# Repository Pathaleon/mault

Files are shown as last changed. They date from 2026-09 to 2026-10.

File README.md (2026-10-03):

# Magic Vault

A TCG card scanner and physical sorter. A webcam identifies cards via AI image embeddings, a rule engine decides which bin each card belongs in, and a feeder and servo mechanism driven by an Arduino or ESP32 physically routes the card there.

## Supported TCGs

Magic: The Gathering, Pokemon, Yu-Gi-Oh, One Piece, Lorcana, Gundam, Flesh and Blood, Riftbound

## MakerWorld

https://makerworld.com/en/models/3066180-tcg-card-sorting-machine

## How it works

1. A feeder mechanism (continuous-rotation servo + roller) pulls a card from the hopper into view of the webcam, into a fixed, per-camera-calibrated scan region (see calibration screen) used as a coarse hint for step 2
2. The browser locates the card's four corners and perspective-dewarps it to a straightened crop, then embeds it, all client-side via [CollectorVision](https://github.com/HanClinto/CollectorVision)'s Cornelius (corner detection) and Milo (embedding) ONNX models running in-browser
3. The embedding is sent to the server for similarity search (or, if the client can't run the on-device models, the raw image is sent for server-side embedding instead)
4. PostgreSQL vector similarity search (pgvector) identifies the card
5. Configurable, per-collection bin rules decide which bin the card should go to
6. The web app sends a serial command to the microcontroller, which drives the trapdoor/paddle/pusher servos to route the card into that bin

## Features

- Live webcam scanning with automatic card detection and identification; captures wait for the card to physically settle at the sensor before the shot is taken
- Multi-TCG support: pluggable card-search adapters per game, with each game's own admin-configurable field definitions driving sorting, filtering, and bin rules
- Rule-based sort bins, grouped by collection, with and/or rule trees across each game's own card fields (color, rarity, price, set, etc.)
- Override rules let a matching bin take priority over ordinary bins. For example, enable **Override rules** on bin 6 with a price condition of **greater than or equal to 1** to send cards worth $1+ there before checking color bins 1–5. If multiple override bins match, the lowest bin number wins; unmatched cards still use the catch-all.
- Card grid sorting (by name, price, rarity, etc.) adapts automatically to whichever game a collection uses
- Multiple collections per organization, each with their own bin configuration and card history
- Remote monitoring: watch an in-progress scan session live from another device
- Discord bot: link a Discord server to an organization with `/link` and a code from the Integrations page, then anyone in it can run `/stats` (optionally scoped to one collection via autocomplete) to check collection stats. Everything else is set up in the app's Integrations page: which channels get every scan and every error or alert (server-wide or per collection), and notification rules that post matching cards to their own channels. No webhook URLs to configure
- Per-organization branding and scanner layout settings
- Feeder, servo, and camera scan-region calibration tools: the camera's capture region can be dragged/resized live against the feed to match different webcam mountings and fields of view
- In-app hardware build guide (`/build`) with bill of materials, wiring diagrams, and assembly instructions

## Stack

- **Web**: React 19, Vite, React Router v7, Tailwind CSS 4, TanStack Query
- **Server**: Hono 4, Drizzle ORM, PostgreSQL (pgvector) — either Neon-hosted or self-hosted
- **Auth**: two interchangeable providers, picked with `AUTH_PROVIDER` — [Neon Auth](https://neon.com) (JWT, hosted) or [own-auth](https://own-auth.com) (self-hosted, bearer tokens against your own Postgres); see [Choosing a provider](#choosing-a-provider)
- **Hardware**: Arduino Uno R4 or ESP32 via Web Serial API (9600 baud), PCA9685 servo driver
- **Monorepo**: Turborepo + pnpm workspaces

## Project structure

```
packages/
├── shared/   @magic-vault/shared - types, constants, evaluate-bin rule engine
├── server/   @magic-vault/server - Hono API, Drizzle schema/db, auth middleware
├── web/      @magic-vault/web    - React SPA (scanner, bins, collections, admin, build guide)
└── bot/      @magic-vault/bot    - Discord bot (slash commands), talks to the server's HTTP API only
firmware/     Arduino/ESP32 sketch (firmware/main/main.ino)
"3d model"/   Printable enclosure/module design (Fusion 360 + .3mf)
drizzle/      Generated SQL migrations
scripts/      Release/version-bump helpers
```

## Getting started

### Choosing a provider

The app needs a Postgres database with pgvector (for card-embedding search) and an identity provider (for login + row-level security), selected by `AUTH_PROVIDER`/`VITE_AUTH_PROVIDER`:

- **`neon`** (default) — a hosted [Neon](https://neon.com) project. A few minutes of console setup, then `pnpm dev`. Neon's free tier is enough for a personal/single-org deployment.
- **`local`** — fully self-hosted, no external account, works offline. `docker-compose.yml` runs the whole stack (Postgres+pgvector, API, web app) with [own-auth](https://own-auth.com) handling sign-up/sign-in against that same self-hosted Postgres.

Both providers read from the same root `.env` (Vite is configured to read up from `packages/web`, so there's no separate `packages/web/.env`):

```bash
cp .env.neon.example .env      # Option A: Neon
cp .env.docker.example .env    # Option B: self-hosted
```

Each file holds only the variables its provider uses, with `AUTH_PROVIDER`/`VITE_AUTH_PROVIDER` already set.

### Option A: Neon

1. Create a Neon project at [console.neon.tech](https://console.neon.tech) (any recent Postgres version works; pgvector ships as a bundled extension).
2. Open the SQL editor on your project's default branch/database and enable pgvector:
   ```sql
   CREATE EXTENSION IF NOT EXISTS vector;
   ```
3. Copy the pooled connection string (Dashboard → Connect) into `DATABASE_URL`.
4. Enable **Neon Auth** for the project (Dashboard → Auth). This provisions the `auth` schema, the `authenticated` Postgres role, and `auth.user_id()` — the row-level-security policies in `drizzle/*.sql` reference these directly, so Auth must be enabled _before_ you run migrations or `db:push` (step below), or they'll fail with an undefined function/role error.
5. From the Auth page, grab:
   - `NEON_AUTH_URL` — the base Auth URL (the server derives the JWKS endpoint and JWT issuer from it: `${NEON_AUTH_URL}/.well-known/jwks.json`)
   - `VITE_NEON_AUTH_URL` — same Auth base URL, used client-side by the Better Auth React client
   - `VITE_NEON_DATA_API_URL` — the project's Data API URL, also from the Auth page
6. Run `pnpm --filter @magic-vault/server db:push` (or `db:generate` + `db:migrate`, see [Database](#database)) to create the schema and RLS policies against your new database.
7. Install and run:
   ```bash
   pnpm install
   pnpm dev        # Vite on :5173, Hono on :3001
   ```

### Option B: Self-hosted (no Neon account, works offline)

1. In `.env` (copied from `.env.docker.example`), fill in:
   - `POSTGRES_PASSWORD` — the local Postgres container's password
   - `OWN_AUTH_TOKEN_PEPPER` — 32+ random bytes; own-auth uses it to hash sessions/tokens/API keys
   - `IMPERSONATION_SECRET` — any random string
   - `MONITOR_LINK_SECRET` — any random string (optional; enables shareable no-login monitor links)
2. Start the stack:
   ```bash
   docker compose up -d
   ```
3. Open `http://localhost:8080` and sign up. The first account ever created on a fresh instance is automatically made platform admin (Games Manager, sync job, impersonation) and gets a default "Home" organisation — from there, add at least one game in the admin Games Manager (`/app/admin`) and run its sync before scanning, or collections/scanning have nothing to match against.

Prices (TCGplayer USD and Cardmarket EUR) come from the `prices` container, which starts with the stack, pulls on start and then checks every `PRICE_SYNC_INTERVAL_HOURS` (6 by default), only downloading what changed upstream. Prices attach to synced cards, so run a game's sync from `/app/admin` first; until then, or until the first pull finishes, cards show no price. Watch it with `docker compose logs -f prices`, or force a full re-pull with `docker compose exec prices node packages/server/dist/scripts/sync-prices.js --force`.

The `server` container applies Drizzle migrations, own-auth's own migrations, and the RLS bootstrap (`packages/server/src/db/bootstrap-local.sql`, run via `pnpm db:migrate-local` — see that script for why plain Postgres needs a few things Neon normally provisions automatically) on every start; all three steps are idempotent.

To grant a _second_ admin, update their row in `platform_user_roles` directly — there's no UI for it yet:

```sql
INSERT INTO platform_user_roles (user_id, role) VALUES ('<their own_auth_users.id>', 'admin')
ON CONFLICT (user_id) DO UPDATE SET role = 'admin';
```

Local mode covers sign-up/sign-in/sign-out/session/org-switch, its own org invite UI, personal API keys, and an org audit log — email verification, profile/password editing, and multi-device session management stay Neon-only for now (see `CLAUDE.md`'s Auth & RLS section).

## Database

```bash
pnpm --filter @magic-vault/server db:generate  # generate a migration from schema changes
pnpm --filter @magic-vault/server db:migrate   # apply migrations
pnpm --filter @magic-vault/server db:push      # push schema directly (dev)
pnpm --filter @magic-vault/server db:studio    # open Drizzle Studio
```

These target whichever Postgres `DATABASE_URL` points at. Self-hosted mode's container applies migrations automatically (see [Option B](#option-b-self-hosted-no-neon-account-works-offline)) — you only need these commands by hand against Neon, or after changing `packages/server/src/db/schema.ts`.

## Deployment

`Dockerfile.server` builds the Hono API (and pre-downloads the pinned CollectorVision Milo model at build time — `packages/server/src/lib/models/model-registry.ts`). `Dockerfile.web` builds the Vite SPA and serves it with nginx (`nginx.conf`); `VITE_API_URL` (and `VITE_AUTH_PROVIDER`) must be supplied as build args since they're baked into the client bundle. `Dockerfile.bot` builds the optional Discord bot — it talks to the server over HTTP (`SERVER_URL`), never the database directly, but the connection is bidirectional: the server also calls back into the bot's own small HTTP server (`BOT_PORT`, exposed to the server as `BOT_URL`) to post every notification into whichever channel was set with `/notify-channel` (errors, jams, sync failures) or `/scan-channel` (card scans), or for Buy Me a Coffee donations (`routes/public.ts`'s `/webhooks/buymeacoffee`, unauthenticated but HMAC-verified rather than org-linked). Both directions share `BOT_API_SECRET`.

> If you're running a Pi-hole or similar DNS-level blocker on your network, it may block `huggingface.co`, which will cause the Milo model download to fail. Allowlist that domain if you hit download errors during the server build/startup.

### Deploying self-hosted

The same `docker compose up -d` flow from [Option B](#option-b-self-hosted-no-neon-account-works-offline) is the production deployment too — just point `WEB_URL` at your public URL, and use a real `POSTGRES_PASSWORD`/`OWN_AUTH_TOKEN_PEPPER`/`IMPERSONATION_SECRET` rather than dev placeholders.

```bash
docker compose up --build -d              # server + web + price sync + local Postgres
docker compose --profile bot up --build -d  # + Discord bot
```

Inside compose the server and bot reach each other by service name (`http://server:3001`, `http://bot:3002`), so the `SERVER_URL`/`BOT_URL` values in `.env` (which point at localhost for `pnpm dev`) are overridden there. If you already run `sync-prices` from your own scheduler, set `PRICE_SYNC_INTERVAL_HOURS=0` so the `prices` container doesn't pull too.

### Deploying with Neon

For the Neon-backed deployment (`AUTH_PROVIDER=neon`, the default), the database and auth still need a [Neon project](#option-a-neon) set up first, and its connection details passed to the server container as env vars (`DATABASE_URL`, `NEON_AUTH_URL`, `WEB_URL`) and to the web build as build args (`VITE_API_URL`, `VITE_NEON_AUTH_URL`, `VITE_NEON_DATA_API_URL`, `VITE_APP_ENV`, `VITE_LATEST_FIRMWARE_VERSION`). A minimal setup:

```bash
docker build -f Dockerfile.server -t magic-vault-server .
docker run -p 3001:3001 --env-file .env magic-vault-server

docker build -f Dockerfile.web \
  --build-arg VITE_API_URL=https://your-api-host \
  --build-arg VITE_NEON_AUTH_URL=$VITE_NEON_AUTH_URL \
  --build-arg VITE_NEON_DATA_API_URL=$VITE_NEON_DATA_API_URL \
  --build-arg VITE_APP_ENV=production \
  --build-arg VITE_LATEST_FIRMWARE_VERSION=1.0.2 \
  -t magic-vault-web .
docker run -p 8080:80 magic-vault-web
```

Point `WEB_URL` (server env) at the public URL of the web container so CORS and Discord monitor-page links resolve correctly, and re-run `db:push`/`db:migrate` against the Neon database as part of your deploy if the schema changed.

The same `docker-compose.yml` from [Option B](#option-b-self-hosted-no-neon-account-works-offline) can wire the three images together this way too (server on :3001, web on :8080, and the optional bot on :3002) — `AUTH_PROVIDER` in `.env` just needs to be `neon` (the default) rather than `local`:

```bash
docker compose up --build
docker compose --profile bot up --build  # + Discord bot
```

`.env` must already point `DATABASE_URL`/`NEON_AUTH_URL` at a real Neon project — the `postgres` service in `docker-compose.yml` still starts alongside it, but sits unused since nothing points at it in this mode.

## Hardware

The full bill of materials, wiring diagrams, and assembly instructions live in the app at `/build`. In short:

- Arduino Uno R4 or ESP32 Dev Module, driving a PCA9685 servo controller over I2C
- 3 positional SG90 servos per sorting module (trapdoor, paddle gate, pusher) plus 1 continuous-rotation SG90 for the feeder — module count is configurable (up to 5 on a single PCA9685) in Calibration
- IR sensor for card-feed detection
- Enclosure and module parts are in `3d model/` (Fusion 360 source + printable `.3mf`)

Upload `firmware/main/main.ino` (requires the ArduinoJson library) to either board via the Arduino IDE — see `/build` for the full flashing steps and per-board pin/wiring differences. The sketch is always compiled for the full module ceiling a single PCA9685 supports — it doesn't need to match how many modules you've actually built, since the app already knows each org's real module count and only ever sends route commands for modules that exist, so you can add modules later without reflashing. It communicates via JSON over USB serial: the web app sends `{"route": {"module": N, "direction": "left"|"right"|"bottom"}}`, resolved from the bin's routing assignment in Calibration, and the board runs the routing sequence. `"bottom"` advances the card through each preceding module (same as `"left"`/`"right"`) and drops it through the target module's own bottom output, rather than a shared catch-all — any bin can be assigned to any module's bottom output.

Where module 1 starts on the PCA9685 is also runtime-configurable, not baked into the firmware: a "PCA9685 channel layout" toggle in Calibration (Standard = channel 0, up to 5 modules; Legacy = channel 4, reserving 0-3 for the status LEDs older firmware drove, up to 3 modules) sends `{"setChannelOffset": N}` once per connection. Orgs with pre-existing module calibration data default to Legacy so already-wired hardware keeps working unchanged; new orgs default to Standard.

## Webcam

Using a Logitech C920, these settings worked best:

Auto Focus: Off
Focus: 50%
Auto Exposure: On
Low Light Compensation: On
Auto White Balance: On
Brightness: 140
Contrast: 140
Saturation: 160
Sharpness: 130

## Licensing

This repository contains multiple components with different licenses.

| Component | License |
| --- | --- |
| Software source code | MIT License |
| 3D models (`/3d model`) | CC BY-NC-SA 4.0 |

See the `LICENSE` file in each directory for the complete license terms.

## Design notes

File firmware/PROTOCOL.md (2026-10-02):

# Sorting Machine Communication Protocol

This documents the serial wire protocol implemented by the sorting
machine's firmware (`main/main.ino`), running on an Arduino Uno R4
(the current build docs/BOM target) or an ESP32 (see the
`ARDUINO_ARCH_ESP32` pin block in `main.ino`). Any client that can open
a serial connection to the device can drive it by following this spec
— it does not assume any particular host language or application.

## Transport

- **9600 baud**. Uno R4 uses native USB CDC serial; most ESP32
  boards instead go through a UART-to-USB bridge chip, which looks
  identical to a client opening the port but does **not** share the
  Uno's reconnect-without-reset behavior described below — a host
  closing and reopening the port on one of those boards does reset the
  sketch (same as a classic Uno), so `{"getStatus": true}` still works
  either way but isn't the only source of a fresh ready/version line.
- ESP32-S2/S3 boards have their own native USB (no bridge chip). They
  must be built with **"USB Mode: Hardware CDC and JTAG"** and **"USB CDC
  On Boot: Enabled"** (`USBMode=hwcdc,CDCOnBoot=cdc` on the arduino-cli
  FQBN - see `firmware-release.yml`), and the client must be plugged into
  the chip's native USB port rather than a secondary UART-only port some
  of these boards also expose. This firmware used to instead own a
  manually-created `USBCDC`/USB-OTG connection so the device could report
  a custom "Mault Card Sorter" name, but that mode's software
  bootloader-reset handshake hits an unresolved upstream bug when
  connected directly to a PC (github.com/espressif/arduino-esp32#10204),
  which made this app's in-browser flashing (`use-serial.tsx`'s
  `flashEsp32`) unreliable. Hardware CDC/JTAG mode's reset handshake
  doesn't hit that bug, at the cost of the device enumerating under a
  fixed Espressif name/VID/PID instead of a custom one. Classic ESP32
  (WROOM/WROVER) has no native USB at all, so its bridge chip's fixed
  descriptor is what shows up instead - not something this firmware can
  change.
- **Framing:** one JSON object per line, terminated by `\n` (`\r` is
  also accepted as a line terminator). Every request produces exactly
  **one** JSON-line response, in the order it was sent — there is no
  request ID, so a client must correlate responses positionally (send
  one command, read one response line, before sending the next).
- **One command at a time, across every transport.** While a command is
  executing (a `route` can take several seconds), the device keeps reading
  input and answers any new line immediately with
  `{"error":"busy","reason":"another command is in progress"}`, without
  running it. That rejection arrives **before** the in-progress command's own
  response, so a client that sent a second command while waiting on a first
  must match the `busy` reply to the second one, not the first. Nothing is
  queued: resend once the first response has arrived. One exception: on the
  Uno R4 WiFi (ArduinoBLE backend), BLE input can't be read while a
  BLE-originated command is running, so a BLE line sent during a BLE command
  is only read (and then run normally) once that command finishes.
- A line longer than 255 characters is discarded and answered with
  `{"error":"command too long"}`.
- Malformed JSON gets `{"error":"invalid JSON","reason":"...","length":N,"received":"<escaped input>"}`.
- An unrecognized (but validly-parsed) command gets `{"error":"unknown command"}`.
- On power-up the device prints
  `{"status":"ready","version":"1.0.2","board":"esp32","id":"A1B2C3"}`
  unprompted, before any command is sent. `board` is `"esp32"` or `"uno_r4"`
  - the app uses it to decide whether the device can be reflashed from the
  browser (ESP32 only) or needs a link to the GitHub repo instead. `id` is
  a short (6 hex character) identifier for this specific physical board -
  the same value over Serial or BLE, and stable across power cycles and
  re-flashes, so a client can key a saved configuration to the board it's
  actually talking to. Sourced from whatever's factory-unique on the board
  (its Wi-Fi/BT MAC on ESP32 and the Uno R4 WiFi - see BLE transport below),
  falling back to a random value generated once and persisted to EEPROM on
  the Uno R4 Minima, which has no radio at all to read an address from.
- One other message is **unsolicited** and can arrive at any time
  between command/response pairs: `{"error":"jam","module":N}`, pushed
  if module *N*'s IR sensor sees a card continuously for 20 seconds
  with no servo activity (firmware 2.2.1+: the clock restarts on any
  servo move, so back-to-back cards fed in during a `feedNext` route never
  add up to a false jam; older firmware timed from when the sensor was
  last seen empty). A client should watch for this
  independently of whatever response it's waiting on. This check is
  purely informational - it doesn't move any servos, since nothing is
  actively trying to sort that card. Paddle-flap recovery only happens
  inline during an active `route`, on a card that fails to advance to
  the next module in time (see `route` below).
- A `route` sent with `"feedNext": true` (firmware 2.1.0+) also emits one
  `{"event":"fed",...}` line **before** its own response (see `route`
  below). Any line carrying an `event` key is never a command's
  response, so a client correlating responses positionally must skip it.

- Uno R4 builds run a hardware watchdog (about 4s). If the board ever
  hangs mid-command (typically a supply dip from servos wedging the MCU or
  its I2C bus), it reboots instead of going silent: the pending command
  never gets a response, USB/BLE drops, and the boot banner is sent again
  once a client reconnects. Configuration is back to defaults after that,
  so a client must re-send it exactly as on a fresh connect.

## BLE transport

ESP32-S3 and Uno R4 WiFi builds also advertise a BLE peripheral, so a client
can drive the device wirelessly instead of over USB - Uno R4 Minima has no
BLE hardware and is Serial-only. This carries the **exact same** line-
delimited JSON protocol documented below; only how bytes get to/from the
device differs. `main.ino`'s two backends (`ble_arduinoble.ino` for the Uno
R4 WiFi, `ble_esp32.ino` for the ESP32-S3) implement this identically from a
protocol standpoint.

- **Service:** the well-known Nordic UART Service (NUS) UUIDs, reused rather
  than inventing custom ones so generic BLE terminal apps (nRF Connect, etc.)
  can talk to the device for debugging without any app-specific tooling.
  - Service: `6E400001-B5A3-F393-E0A9-E50E24DCCA9E`
  - RX characteristic (write / write-without-response — commands in):
    `6E400002-B5A3-F393-E0A9-E50E24DCCA9E`
  - TX characteristic (notify — responses and unsolicited messages out):
    `6E400003-B5A3-F393-E0A9-E50E24DCCA9E`
- **Framing:** identical to Serial — one JSON object per line, `\n`-
  terminated. A single command or response line is **not** guaranteed to
  arrive in one BLE write/notify packet: both directions get chunked to the
  connection's negotiated MTU (the device chunks conservatively at 20 bytes
  unless testing shows a given board/central negotiates higher), so a client
  must reassemble by simply appending received bytes to a buffer and
  splitting on `\n`, exactly as it already does for Serial's byte stream.
- **Response routing:** a command's response is sent back only on the
  transport it arrived on — if both Serial and BLE are connected at once,
  each keeps its own independent request/response correlation (the protocol
  has no request IDs, so a client must still send one command and read one
  response before sending the next — see Transport above). The boot banner
  and the unsolicited `{"error":"jam",...}` message are the exception: they
  broadcast to every currently-connected transport, not just one.
- **Reliability:** BLE notifications aren't guaranteed delivery. A dropped
  chunk mid-line corrupts that one response; a client's existing timeout-
  based recovery (waiting for a response line, per the framing note above)
  handles this as a failed/garbled response, but there's no automatic retry
  of the specific request. This matches how generic BLE UART bridges behave.
- **Power-only operation:** BLE works with no USB host at all (e.g. only
  VIN powered). On boot the firmware waits at most 1.5s for a USB serial
  host before starting BLE, and on ESP32-S3 Hardware CDC builds USB writes
  never block when no host is attached. Without a USB host the boot banner
  only goes out over BLE once a central connects, so a client should send
  `{"getStatus": true}` after connecting.
- **Advertised name:** `"Mault Sorter XXXXXX"`, where `XXXXXX` is the same
  `id` reported in `getStatus`/the boot banner (see Transport above) - on
  these two boards, sourced from the BLE MAC (`BLE.address()` on the Uno R4
  WiFi's ArduinoBLE backend, `esp_read_mac(..., ESP_MAC_WIFI_STA)` on the
  ESP32-S3 Bluedroid backend, read before BLE even advertises). This exists
  so multiple physical units show up as distinct entries in a phone/OS
  Bluetooth picker before a client ever connects to one.

## Hardware model

- A **module** is one physical sorting stage: three positional SG90
  servos (`bottom` = trapdoor, `paddle` = gate, `pusher` = arm) plus its
  own IR sensor, occupying 3 consecutive channels on the onboard PCA9685
  servo driver (module *N* → channels `(N-1)*3 .. (N-1)*3+2`, shifted by
  the active channel offset).
- The **feeder** is a separate continuous-rotation servo on the channel
  right after the last addressable module, plus its own hopper IR sensor
  (separate from any module's IR) that reports whether cards remain in
  the stack.
- The channel offset (set via `setChannelOffset`) is `0` ("standard",
  up to 5 modules) or `4` ("legacy", up to 3 modules — channels 0-3 are
  reserved for older status LEDs on that layout). It must be set once
  per connection, before any other command, because it determines how
  many modules exist and therefore which module numbers are valid.
- The firmware has no concept of a "bin" — only modules and directions.
  A client that wants bin-style routing (mapping arbitrary logical bins
  to physical outputs) needs to keep that mapping on its own side and
  translate it to a `route` command.

## Recommended connection sequence

1. Open the serial port at 9600 baud.
2. Send `{"getStatus": true}` and read the response to confirm the
   device is alive and check its firmware `version`. Also useful after
   reopening a port without a physical power cycle: on native-USB boards
   (Uno R4) the sketch doesn't reset and won't print a fresh boot
   message on its own, so this is the only way to get one; on
   UART-bridge boards (most ESP32s) reopening does reset the sketch and
   print one unprompted, but sending this is still harmless and confirms
   the version either way.
3. Send `{"setChannelOffset": 0}` or `{"setChannelOffset": 4}` depending
   on which physical layout the machine uses.
4. Optionally push any calibration you want to (re)apply via `setConfig`
   / `setFeederConfig` — the device only remembers calibration for as
   long as it stays powered, so a client is responsible for restoring it
   after every reset.
5. Optionally run `{"test": true}` to sanity-check every servo before
   normal operation.

## Commands

All requests are single-line JSON objects, keyed on which top-level
field is present.

### `getStatus`
```json
{"getStatus": true}
```
→ `{"status":"ready","version":"1.0.2","board":"esp32","id":"A1B2C3"}`

Firmware 2.2.2+ adds `"ble"` to this line and to the boot banner:
`"advertising"` (BLE is up and discoverable), `"connected"` (a central is
connected, so the device isn't advertising, since ArduinoBLE and this
firmware's Bluedroid backend accept one connection at a time),
`"unavailable"` (the BLE stack failed to start, e.g. the Uno R4 WiFi's
co-processor didn't answer `BLE.begin()` after 5 attempts; the device keeps
working over Serial), or `"none"` (a board with no BLE hardware, such as the
Uno R4 Minima).

### `setChannelOffset`
```json
{"setChannelOffset": 0}
```
`0` = standard layout, `4` = legacy layout. Also resets every servo to
neutral. → `{"status":"ok"}`

### `test`
```json
{"test": true}
```
Runs a full self-test sequence: opens every module's bottom + paddle →
sweeps every pusher left → sweeps every pusher right → resets all to
neutral → briefly spins the feeder (500ms) → stops it.
→ `{"status":"test_complete"}`

Refuses to run (and reports which module) if any module's gate sensor
already reads a card present, since the sequence sweeps every
trapdoor/paddle/pusher without regard for something already sitting in the
mechanism - clear it first (`clearDevice`) and retry. Doesn't check the
hopper sensor, since cards waiting to be fed are a normal state, not a jam.
→ `{"error":"module 2 sensor is blocked - clear the device before testing","module":2}`

### `neutral`
```json
{"neutral": true}
```
Resets every module's bottom/paddle/pusher to closed/closed/neutral and
stops the feeder. → `{"status":"ok"}`

### `clearDevice`
```json
{"clearDevice": true}
```
Opens **every** module's bottom trapdoor at once (useful for flushing a
physically stuck card), then resets to neutral. → `{"status":"cleared"}`

### `servo` (manual single-servo move)
```json
{"servo": "bottom", "module": 1, "position": "open"}
```
or, to bypass calibrated positions and drive a raw pulse directly:
```json
{"servo": "bottom", "module": 1, "value": 250}
```
- `servo`: `"bottom" | "paddle" | "pusher"`
- `position`: `"open" | "closed"` (bottom/paddle), `"left" | "neutral" | "right"` (pusher)
- `value`: raw PWM pulse, clamped to `120–490`

→ `{"status":"ok","servo":"bottom","module":1}`, or
`{"error":"servo must be bottom, paddle, or pusher"}` /
`{"error":"invalid position"}` / `{"error":"module must be 1 to N"}`

#### Push safeguard (firmware 2.2.0+, always on since 2.3.0)

A pusher never moves off neutral unless its module's side paddle has been
commanded to its calibrated `paddleOpen` position and has had
`DELAY_PADDLE` (300 ms) to get there. The firmware has no paddle position
sensor, so it tracks the last position it commanded: any other paddle
pulse, or the idle servo release, counts as not open.

Since 2.3.0 this is enforced inside the firmware's single servo write path,
so it covers every pusher move (`servo`, `channel` writes that land on a
module's pusher channel, `route`, `pushTest`, the connect `test`) whether or
not a card is on the platform. Instead of refusing, a pusher move with the
paddle not known to be down lowers the paddle itself, waits out the rest of
`DELAY_PADDLE`, then moves the pusher, so the command just takes up to
300 ms longer and the paddle is left lowered. Returning a pusher to neutral
never touches the paddle.

2.2.x only applied the check while the module's IR sensor read a card, and
refused the move with
`{"error":"push_blocked","reason":"lower the side paddle before pushing a card","module":N}`
instead of lowering the paddle. 2.3.0+ never sends `push_blocked`; clients
still handle it for older firmware.

### `channel` (raw PCA9685 channel test)
```json
{"channel": 7, "value": 300}
```
Drives PCA9685 channel `channel` (0-15) at raw pulse `value` directly,
bypassing the module/servo mapping (`getChannel()`) and its module-range
validation entirely — unlike `servo` above, this works on a channel that
isn't wired into any module yet. For verifying a servo/channel works, or
finding which channel a given wire is on, during assembly or troubleshooting.
- `value`: raw PWM pulse, same `120–490` range as `servo`'s `value`
→ `{"status":"ok","channel":7}`, or `{"error":"channel must be 0 to 15"}`

### `channelStop`
```json
{"channelStop": 7}
```
Cuts PWM on a raw channel — needed after testing a continuous-rotation servo
via `channel` above, since (like the feeder) it has no neutral pulse that
stops it on its own. → `{"status":"ok","channel":7}`, or
`{"error":"channel must be 0 to 15"}`

### `setConfig` (calibration values — does not move anything)
```json
{
  "setConfig": {
    "module": 1,
    "bottomClosed": 400, "bottomOpen": 150,
    "paddleClosed": 420, "paddleOpen": 150,
    "pusherLeft": 150, "pusherNeutral": 230, "pusherRight": 300,
    "pusherHoldDuration": 150,
    "paddleCloseDelay": 150
  }
}
```
Every field except `module` is optional — omitted fields keep their
current stored value. `bottomClosed`/`bottomOpen`/`paddleClosed`/`paddleOpen`/
`pusherLeft`/`pusherNeutral`/`pusherRight` are raw PWM pulse values (same
`120–490` range as `servo`'s `value`), one pair/triple per servo defining
its two or three named positions. `pusherHoldDuration` and
`paddleCloseDelay` are different: they're durations in milliseconds, not
pulses - see `route` below for how they're used. `pusherHoldDuration`
defaults to 150. → `{"status":"ok","module":1}`

### `pushTest` (tune push timings without a card)
```json
{"pushTest": {"module": 2, "direction": "left", "pusherHoldDuration": 150, "paddleCloseDelay": 1000}}
```
Runs only the left/right push step of `route` on `module`: opens its
paddle, fires the pusher, retracts it after `pusherHoldDuration` ms, and
closes the paddle `paddleCloseDelay` ms after the pusher fired. No feed and
no IR checks. Both timings are optional (default: the module's stored
`setConfig` values) and clamped to 0–5000 ms, so unsaved values can be
tried before committing them with `setConfig`.
→ `{"status":"pushed","module":2,"direction":"left"}`, or
`{"error":"module must be 1 to N"}` / `{"error":"direction must be left or right"}`.
Firmware older than this command answers `{"error":"unknown command"}`.

### `feeder`
```json
{"feeder": true}
```
Runs the feed sequence until module 1's IR sensor detects a card, the
hopper is found empty, or it times out.
→ `{"status":"ok","detected":true,"empty":false}`,
or on failure a `{"error":"...","empty":true|false}` shape (see Errors below).

### `feederValue` (raw PWM preview)
```json
{"feederValue": 315}
```
Drives the feeder servo at a raw pulse directly. **Does not auto-stop** —
a client must follow up with `feederStop` (or any other command that
resets state, like `neutral` or `test`) to stop the motor.
→ `{"status":"ok"}`

### `feederStop`
```json
{"feederStop": true}
```
Immediately cuts PWM on the feeder channel. → `{"status":"ok"}`

### `setFeederConfig`
```json
{
  "setFeederConfig": {
    "speed": 250,
    "duration": 3000,
    "pulseDuration": 80,
    "pauseDuration": 0,
    "settleDuration": 500,
    "reverseSpeed": 333,
    "reverseDuration": 0
  }
}
```
All fields optional/partial, same merge behavior as `setConfig`. Stops
the feeder as a side effect. → `{"status":"ok"}`

| Field | Meaning |
|---|---|
| `speed` | Raw PWM pulse driving the feeder motor while running |
| `duration` | Overall timeout (ms) to detect a card before giving up |
| `pulseDuration` | If `> 0`, run in pulsed mode: drive for this many ms, then check IR (`0` = continuous-drive mode instead) |
| `pauseDuration` | Pause (ms) between pulses in pulsed mode |
| `settleDuration` | Extra run time (ms) after detection, only when the hopper is now empty, so the last card (with nothing behind it) still fully clears into module 1 |
| `reverseSpeed` | Raw PWM pulse driving the feeder motor backward during rollback (the other side of the motor's stop point from `speed`). Firmware 2.4.0+ |
| `reverseDuration` | Rollback time (ms): once a feed delivers a card to module 1 and cards remain in the hopper, the roller runs backward this long so the next card, dragged forward by friction, is pulled back instead of creeping in behind it (a double feed). `0` (the default) turns it off. Firmware 2.4.0+; older firmware ignores both fields |

### `readIR`
```json
{"readIR": true}
```
→ `{"status":"ok","ir":[true,false,false],"hopper":true}`

`ir` is one boolean per addressable module (array length = the current
max module count for the active channel offset), `true` meaning a card
is present. `hopper` is `true` while cards remain in the feeder stack.

### `route` (the normal per-card sorting command)
```json
{"route": {"module": 2, "direction": "left"}}
```
- `direction`: `"left" | "right" | "bottom"`
- Runs the feeder first, then routes the card: opens each preceding
  module's bottom in turn to advance the card (confirming arrival via
  that module's IR sensor, 3s timeout each step - if a step times out,
  flaps that module's paddle once, the same recovery `jam` handling uses,
  then gives the card one more 3s window before reporting failure), then
  either opens the target module's paddle and drives its pusher in the
  requested direction (`"left"`/`"right"`), or opens just the target
  module's own bottom to drop the card there (`"bottom"`).
- For a `"left"`/`"right"` push, two timings run independently once the
  pusher fires: the pusher itself returns to neutral after
  `pusherHoldDuration` ms (per-module, via `setConfig`: long enough to
  complete its stroke and fling the card, short enough not to stall
  against the mechanical stop for long); the
  target module's paddle instead closes `paddleCloseDelay` ms after the
  pusher fired (per-module, via `setConfig`) - independent of the pusher's
  own timing, so the paddle can be tuned to stay open longer than the
  pusher is held, to make sure the card has actually cleared before the
  gate closes.
- A card destined for a module's bottom output doesn't need to be the
  last module — any module can be targeted with `direction: "bottom"`.

→ `{"status":"routed","module":2,"direction":"left"}` on success.

#### `feedNext` (firmware 2.1.0+)
```json
{"route": {"module": 3, "direction": "left", "feedNext": true}}
```
Feeds the next card into module 1 as part of this route, so a client can
start scanning it while this card is still travelling. Once the routed
card has reached module 2 and module 1's IR sensor reads clear, module 1's
bottom closes and the feeder runs. If the target is module 1 itself (or
module 1's sensor never clears within 3s), the feed runs after the card
has been pushed/dropped instead. Either way, exactly one extra line is
sent before the final response, from the same transport:

- `{"event":"fed","status":"ok","detected":true,"empty":false}` when a card arrived at module 1
- `{"event":"fed","error":"empty: feeder hopper is out of cards","empty":true}` or
  `{"event":"fed","error":"timeout: feeder did not deliver card to module 1","empty":false}` otherwise

A failed mid-route feed doesn't abort the route. The final response then
carries `"fedNext":true`, e.g.
`{"status":"routed","module":3,"direction":"left","fedNext":true}`, so a
client can tell a firmware that honored the flag from an older one that
silently ignored it (older firmware sends no event and no `fedNext`). If
the route itself fails after the mid-route feed, the `fed` event has
already been sent and the next card is sitting in module 1. Allow extra
response time for the feed (the web client waits 25s instead of 15s).

## Error responses

| Response | When |
|---|---|
| `{"error":"module must be 1 to N"}` | `module` outside the valid range for the current channel offset |
| `{"error":"channel must be 0 to 15"}` | `channel`/`channelStop` outside the PCA9685's addressable range |
| `{"error":"servo must be bottom, paddle, or pusher"}` | invalid `servo` field |
| `{"error":"invalid position"}` | `position` not valid for that servo type |
| `{"error":"direction must be left, right, or bottom"}` | invalid `direction` in `route` |
| `{"error":"empty: feeder hopper is out of cards","empty":true}` | feed attempted with no cards in the hopper |
| `{"error":"timeout: feeder did not deliver card to module 1","empty":false}` | feeder ran its full configured `duration` without module 1's IR triggering |
| `{"error":"timeout: no card detected at module N"}` | during routing, a card didn't advance to module *N* in time (3s, plus one paddle-flap retry and another 3s) |
| `{"error":"invalid JSON","reason":"...","length":N,"received":"..."}` | line didn't parse as JSON |
| `{"error":"command too long"}` | line exceeded 255 characters |
| `{"error":"push_blocked","reason":"lower the side paddle before pushing a card","module":N}` | firmware 2.2.x only: a `servo`/`channel` pusher move while a card is on module *N*'s platform and its side paddle isn't down (see Push safeguard) |
| `{"error":"busy","reason":"another command is in progress"}` | a line arrived while another command (from any transport) was still executing; the line was not run |
| `{"error":"unknown command"}` | valid JSON, but no recognized top-level key |
| `{"error":"jam","module":N}` | **unsolicited** — module *N*'s IR saw a card continuously for 20s with no servo activity (informational only - no paddle-flap is attempted since nothing is actively sorting) |

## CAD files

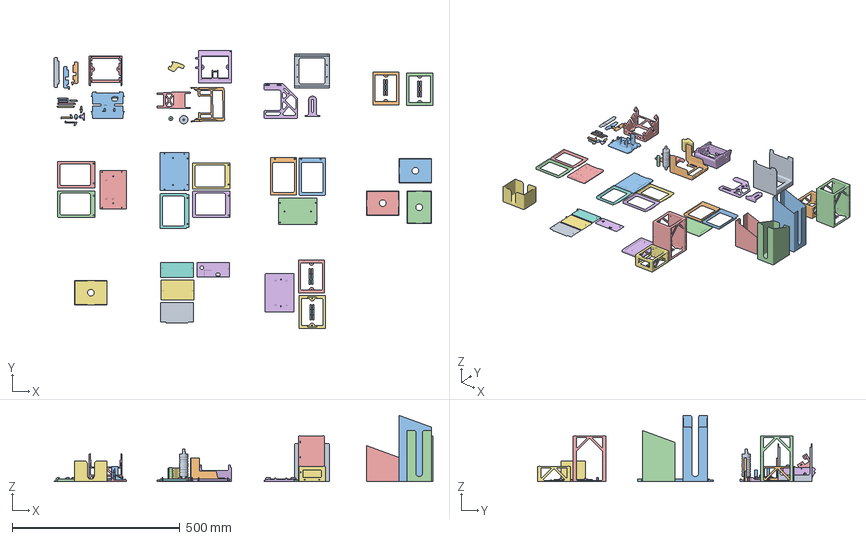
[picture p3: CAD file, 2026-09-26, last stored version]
3d model/card_sorter.3mf
1129.3 x 828.7 x 197.3 mm
shroud
hopper
card_sleeve_lg
card_sleeve_md
card_sleeve_small
camera_mount
card_sleeve_end
base plate end wing
roller
generic base wing 2 x 2
generic base wing 3 x 2
generic base plate wing 2
generic base plate wing 3
module_pin x 24
back plate feeder
back plate
front plate
base x 3
base_end
generic base
base esp32 breakout
module_base
pusher_servo_arm
sides_servo_arm
bottom_servo_arm
right_pusher
left_pusher
platform
bottom_paddle_arm
left_paddle_arm
pusher_arm x 2
right_paddle_arm
bottom_paddle
left_paddle
right_paddle
hopper roller
variable hopper wall
feeder_base
esp 32 breakout base
feeder riser

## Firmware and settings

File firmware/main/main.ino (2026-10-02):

#include <ArduinoJson.h>
#include <EEPROM.h>
#include <Wire.h>
#include <ctype.h>
#include <Adafruit_PWMServoDriver.h>
#if defined(ARDUINO_ARCH_ESP32)
#include "esp_mac.h"
#else
#include <WDT.h>
#endif

// S2/S3 boards must be built with "USB Mode: Hardware CDC and JTAG" and
// "USB CDC On Boot: Enabled" (Arduino IDE Tools menu, or
// USBMode=hwcdc,CDCOnBoot=cdc on the arduino-cli FQBN - see
// firmware-release.yml) - the core then maps Serial to the chip's
// hardware USB-Serial/JTAG peripheral automatically, no app code needed.
// This used to instead be a manually-owned USBCDC/USB-OTG connection so
// the device could report a custom product/manufacturer name, but that
// mode's software bootloader-reset handshake hits an unresolved upstream
// bug when connected directly to a PC rather than through a USB hub
// (reset_sem timeout in usb_switch_to_cdc_jtag() -
// github.com/espressif/arduino-esp32/issues/10204), which made this
// app's in-browser flashEsp32 unreliable. Hardware CDC/JTAG mode's reset
// handshake doesn't hit that bug, at the cost of a fixed Espressif
// device name/VID/PID instead of a custom one. Classic ESP32
// (WROOM/WROVER) and the Uno R4 Minima have no native USB either way and
// are unaffected - Serial there is always the UART bridge chip.

#define FIRMWARE_VERSION "2.4.0"

// Reported in getStatus/boot so the app knows how (or whether) it can
// update the device - only the ESP32 build can be reflashed from the
// browser (see use-serial.tsx's flashEsp32).
#if defined(ARDUINO_ARCH_ESP32)
#define BOARD_TYPE "esp32"
#else
#define BOARD_TYPE "uno_r4"
#endif

// Which (if any) BLE backend this build compiles in. ARDUINO_UNOWIFIR4 is the
// Renesas core's board macro for the arduino:renesas_uno:unor4wifi FQBN
// (mirroring ARDUINO_MINIMA for the plain arduino:renesas_uno:minima variant,
// which has no BLE hardware and must stay Serial-only) - confirmed correct
// by a real compile against the installed core (selects BLE_BACKEND_ARDUINOBLE
// as expected for the WiFi board). Only the S3 gets a BLE backend on the
// ESP32 side - classic ESP32 (WROOM/WROVER) isn't a build target today (see
// firmware-release.yml) and its Bluedroid BLE would need its own IR pin map
// consideration if that ever changes.
#if defined(ARDUINO_UNOWIFIR4)
#define BLE_SUPPORTED 1
#define BLE_BACKEND_ARDUINOBLE 1
#elif defined(ARDUINO_ARCH_ESP32) && defined(CONFIG_IDF_TARGET_ESP32S3)
#define BLE_SUPPORTED 1
#define BLE_BACKEND_ESP32 1
#else
#define BLE_SUPPORTED 0
#endif

// These must be #included here (not just in ble_arduinoble.ino/ble_esp32.ino,
// even though that's where they're actually used) - the Arduino builder
// inserts its auto-generated function prototypes for the WHOLE merged
// sketch at one point anchored to this file's own leading #include block,
// before any other tab's #includes take effect. A prototype referencing
// BLEDevice/BLECharacteristic/etc. hoisted to that point fails to compile
// ("was not declared in this scope") unless these headers are already
// visible there.
#if BLE_BACKEND_ARDUINOBLE
#include <ArduinoBLE.h>
#elif BLE_BACKEND_ESP32
#include <BLE2902.h>
#include <BLEDevice.h>
#include <BLEServer.h>
#include <BLEUtils.h>
#endif

Adafruit_PWMServoDriver pwm = Adafruit_PWMServoDriver();

// Short, human-distinguishable ID identifying this specific physical board -
// the same value regardless of which transport (Serial or BLE) a client
// reads it over, and stable across power cycles/resets, so the app can key a
// saved device record to a specific unit and multiple units show up as
// distinct entries in a phone/OS Bluetooth picker before ever connecting.
// Populated once from setup(), before the boot banner is printed, via the
// best source available on the board:
//   - ESP32 (any variant): the factory Wi-Fi/BT MAC (setDeviceIdFromMac()
//     below), read unconditionally - present on the silicon regardless of
//     whether this build even compiles in a BLE backend (see BLE_SUPPORTED).
//   - Uno R4 WiFi: also MAC-derived, but only readable after BLE.begin()
//     talks to the onboard co-processor, so it's set from inside bleInit()
//     (see ble_arduinoble.ino) instead of here.
//   - Uno R4 Minima (no radio of any kind): falls back to
//     loadOrCreateDeviceId() below, which persists a random one-time-
//     generated ID to EEPROM/data flash - the only board with nothing
//     factory-unique to read.
char deviceId[7] = "";

// Formats a colon-separated MAC string ("aa:bb:cc:dd:ee:ff") into deviceId as
// its last 6 hex characters, uppercased and with colons stripped - plenty of
// entropy to tell boards apart on a bench without needing the full address.
void setDeviceIdFromMac(const char* mac) {
  char stripped[13];
  int len = 0;
  for (const char* p = mac; *p && len < 12; p++) {
    if (*p != ':') stripped[len++] = (char)toupper((unsigned char)*p);
  }
  stripped[len] = '\0';
  int start = len > 6 ? len - 6 : 0;
  strncpy(deviceId, stripped + start, 6);
  deviceId[6] = '\0';
}

#if defined(ARDUINO_ARCH_ESP32)
// Every ESP32 (classic or S3) has a factory-programmed Wi-Fi/BT MAC
// regardless of whether this build even compiles in the BLE backend
// (BLE_SUPPORTED is 0 for classic ESP32 - see below) - ESP_MAC_WIFI_STA is
// readable unconditionally, unlike the Uno R4 WiFi's BLE.address(), which
// needs the co-processor initialized first.
void initDeviceIdFromEspMac() {
  uint8_t mac[6];
  esp_read_mac(mac, ESP_MAC_WIFI_STA);
  char macStr[18];
  snprintf(macStr, sizeof(macStr), "%02X:%02X:%02X:%02X:%02X:%02X", mac[0],
           mac[1], mac[2], mac[3], mac[4], mac[5]);
  setDeviceIdFromMac(macStr);
}
#endif

#define DEVICE_ID_EEPROM_ADDR 0
// Marks that a device ID was already generated and stored, so a re-flash or
// reset doesn't hand out a fresh random one - written only once, on this
// board's actual first boot.
#define DEVICE_ID_EEPROM_MAGIC 0xA5

// Last-resort fallback for a board with no factory-unique hardware ID to
// read at all (only the Uno R4 Minima, which has no radio - see deviceId's
// comment above). Unlike servo calibration, which this firmware intentionally
// does NOT remember across power-off (see setConfig's docs in PROTOCOL.md), a
// board's identity has to survive a reset or it's useless for keying a saved
// device record to a specific physical unit - so this one value does get
// persisted, to EEPROM (which the Renesas UNO R4 core emulates over its
// internal data flash).
void loadOrCreateDeviceId() {
#if defined(ARDUINO_ARCH_ESP32)
  EEPROM.begin(8);
#endif

  if (EEPROM.read(DEVICE_ID_EEPROM_ADDR) == DEVICE_ID_EEPROM_MAGIC) {
    for (int i = 0; i < 6; i++) {
      deviceId[i] = (char)EEPROM.read(DEVICE_ID_EEPROM_ADDR + 1 + i);
    }
    deviceId[6] = '\0';
    return;
  }

  randomSeed(micros());
  const char hexDigits[] = "0123456789ABCDEF";
  for (int i = 0; i < 6; i++) {
    deviceId[i] = hexDigits[random(0, 16)];
  }
  deviceId[6] = '\0';

  EEPROM.write(DEVICE_ID_EEPROM_ADDR, DEVICE_ID_EEPROM_MAGIC);
  for (int i = 0; i < 6; i++) {
    EEPROM.write(DEVICE_ID_EEPROM_ADDR + 1 + i, deviceId[i]);
  }
#if defined(ARDUINO_ARCH_ESP32)
  EEPROM.commit();
#endif
}

// PCA9685 channels: each module uses 3 consecutive channels (bottom, paddle,
// pusher) starting at moduleChannelOffset; the feeder gets the next channel
// after the last addressable module. Offset is set via
// {"setChannelOffset": N} - 0 for standard wiring, 4 for legacy hardware
// that reserves channels 0-3 for old status LEDs (caps at 3 modules instead
// of 5). MAX_MODULES only sizes arrays; maxModuleForOffset() is the actual
// addressable count for the current offset.
#define MAX_MODULES 5
int moduleChannelOffset = 0;

// IR sensor pins, one per module (active LOW: pin reads LOW when a card is
// present).
#if defined(CONFIG_IDF_TARGET_ESP32S3)
// ESP32-S3 pins avoid strapping (0, 3, 45, 46), the native USB D-/D+ pair
// (19, 20), the default I2C pins used to
// wire the PCA9685 (8, 9 - see Wiring), the USB-UART bridge (43, 44), and
// integrated flash/PSRAM (26-37).
const int IR_PINS[MAX_MODULES] = {4, 5, 6, 7, 15};
#define IR_PIN_HOPPER 16
#elif defined(ARDUINO_ARCH_ESP32)
// Classic ESP32 (WROOM/WROVER) pins avoid strapping (0, 2, 5, 12, 15),
// flash (6-11), WROVER PSRAM (16, 17), and input-only pins (34-39, no
// internal pull-up) - renumber for other ESP32 variants as needed.
const int IR_PINS[MAX_MODULES] = {18, 19, 23, 25, 26};
#define IR_PIN_HOPPER 27
#else
const int IR_PINS[MAX_MODULES] = {2, 3, 4, 6, 7};
#define IR_PIN_HOPPER 5
#endif

#define IR_TIMEOUT_MS 3000
#define SERIAL_CONNECT_WAIT_MS 1500

// Uno R4 only (its WDT tops out at ~5.6s). Every blocking wait goes through
// waitMs(), which keeps it fed, so it only fires if the board truly hangs,
// e.g. after a supply dip from servos moving together leaves the MCU or
// its I2C peripheral wedged. The reboot drops USB, so the app sees a
// disconnect instead of a sorter that silently stops answering.
#define WATCHDOG_TIMEOUT_MS 4000

#define SERVO_PWM_FREQ 50
// Gap between consecutive servo moves in setAllNeutral(), so a full reset
// doesn't start every servo at once and pull the supply down.
#define SERVO_STAGGER_MS 25

// If a card sits at a module this long with no route in progress, something's
// stuck - just report it. Paddle-flap recovery only happens while a route is
// actively moving a card through (see routeCard()) - something merely
// resting on a sensor while the device is idle (a card left in a tray, a
// hand, dust) isn't a jam a wiggle should react to.
#define MODULE_JAM_TIMEOUT_MS 20000
#define SERVO_IDLE_RELEASE_MS 1500

// The Arduino builder auto-generates a forward declaration for every
// function and hoists all of them to one insertion point near the top of
// the file - earlier than this enum, since setDeviceIdFromMac() and other
// functions above already exist there. That hoisted `FeedResult runFeeder();`
// then fails to compile ("FeedResult does not name a type") on cores whose
// bundled ctags can't resolve the return type at that point (this is the
// case on ESP32, not on the Uno R4 board's core). Writing our own prototype
// below stops the builder from generating a conflicting one, since it skips
// auto-prototyping any function that already has an explicit declaration.
enum FeedResult { FEED_DETECTED, FEED_TIMEOUT, FEED_EMPTY };
FeedResult runFeeder();
void printFeedFailureFields(FeedResult feedResult, Print& reply);

// Largest module number whose 3 channels, plus one feeder channel right
// after it, still fit in channels [offset, 15].
int maxModuleForOffset() {
  int n = (15 - moduleChannelOffset) / 3;
  return n < 0 ? 0 : n;
}

int irPin(int module) {
  return IR_PINS[module - 1];
}

bool hopperHasCards() {
  return digitalRead(IR_PIN_HOPPER) == LOW;
}

void feedWatchdog() {
#if !defined(ARDUINO_ARCH_ESP32)
  WDT.refresh();
#endif
}

void pumpInput();
extern bool commandInProgress;

void waitMs(unsigned long ms) {
  unsigned long start = millis();
  while (millis() - start < ms) {
    feedWatchdog();
    if (commandInProgress) pumpInput();
    unsigned long left = ms - (millis() - start);
    delay(left < 50 ? left : 50);
  }
  feedWatchdog();
}

bool waitForCard(int module, int timeoutMs = IR_TIMEOUT_MS) {
  unsigned long start = millis();
  while (digitalRead(irPin(module)) == HIGH) {
    if (millis() - start > (unsigned long)timeoutMs) return false;
    waitMs(5);
  }
  return true;
}

bool waitForClear(int module, int timeoutMs = IR_TIMEOUT_MS) {
  unsigned long start = millis();
  while (digitalRead(irPin(module)) == LOW) {
    if (millis() - start > (unsigned long)timeoutMs) return false;
    waitMs(5);
  }
  return true;
}

// Returns the first module number (1-based) whose gate sensor currently
// reads a card present, or 0 if none are blocked. Used to refuse to run
// the mechanical self-test with something already sitting in the
// mechanism - the test sweeps every trapdoor/paddle/pusher without regard
// for a card that's already there. Doesn't check the hopper sensor, since
// cards waiting in the hopper are a normal, expected state, not a jam.
int findBlockedModule() {
  for (int m = 1; m <= maxModuleForOffset(); m++) {
    if (digitalRead(irPin(m)) == LOW) return m;
  }
  return 0;
}

struct ModuleConfig {
  int bottomClosed, bottomOpen;
  int paddleClosed, paddleOpen;
  int pusherLeft, pusherNeutral, pusherRight;
  int pusherHoldDuration;  // ms the pusher stays extended before
                           // returning to neutral
  int paddleCloseDelay;  // ms from the pusher firing until this module's
                          // paddle closes again - independent of
                          // DELAY_PUSHER_HOLD, which governs when the pusher
                          // itself returns to neutral (see routeCard())
};

ModuleConfig moduleConfig[MAX_MODULES];

struct FeederConfig {
  int speed;
  int duration;        // overall timeout (ms) before giving up
  int pulseDuration;    // ms per pulse; 0 = continuous feed, no pulsing
  int pauseDuration;    // ms between pulses (IR checked after each stop)
  int settleDuration;   // extra ms to feed once IR sees the card, so it
                         // clears the sensor instead of stopping right on it
  int reverseSpeed;
  int reverseDuration;
};

FeederConfig feederConfig = {315, 1000, 40, 100, 100, 295, 0};

// Routing delays (ms) — tune to match your hardware timing
#define DELAY_CARD_ENTER   300  // time for card to settle after target bottom opens
#define DELAY_PADDLE       300  // time for paddle to engage
#define DELAY_PUSH         600  // time for pusher to complete its stroke
// A servo is positional, not velocity-controlled - commanding it to (or past)
// a hard mechanical stop makes it stall at full torque against that stop for
// as long as it's held there, not just for the instant it takes to arrive.
// The fling itself happens in the first ~100ms of travel; every extra ms
// held against the stop after that is pure stress on the horn/shaft with no
// benefit, and is what walks the horn loose over repeated cycles. Keep this
// well under DELAY_PUSH and tune it on real hardware: long enough for the
// pusher to complete its swing and actually fling the card, short enough
// that it's released before it's spent much time stalled at the stop.
#define DELAY_PUSHER_HOLD  150

#define MAX_CMD_LEN 255

// One InputState per transport - a command's response must go back out the
// same transport it arrived on (the protocol has no request IDs; a client
// correlates request/response positionally, see PROTOCOL.md), so a partial
// line from one transport must never get spliced with a partial line from
// the other.
struct InputState {
  char buf[MAX_CMD_LEN + 1];
  uint8_t len = 0;
  bool overflowed = false;
};
InputState serialInput;
#if BLE_SUPPORTED
InputState bleInput;
#endif

// Manual prototype: the Arduino builder's auto-generated forward
// declarations are hoisted above this point in the file (before
// InputState even exists there), which fails to compile for any function
// taking it by reference. An explicit prototype here - matching feedByte()'s
// eventual definition further down - stops the builder from generating its
// own broken one for it.
void feedByte(InputState& s, char c, Print& reply);

unsigned long modulePresentSince[MAX_MODULES] = {0};
unsigned long moduleJamAlertedFor[MAX_MODULES] = {0};

int getChannel(int module, int servoOffset) {
  return moduleChannelOffset + (module - 1) * 3 + servoOffset;
}

int getFeederChannel() {
  return moduleChannelOffset + maxModuleForOffset() * 3;
}

unsigned long lastServoMoveAt = 0;
bool servosReleased = false;

void configureI2c() {
  // Renesas' Wire ignores setWireTimeout's reset flag, so a timed-out
  // transaction leaves the peripheral wedged; recoverServoDriver() restarts
  // it instead. arduino-esp32's TwoWire has no setWireTimeout at all, only
  // a millisecond setTimeout, and recovers its own bus.
#if defined(ARDUINO_ARCH_ESP32)
  Wire.setTimeout(25);
#else
  Wire.setWireTimeout(25000, true);
#endif
}

void initServoDriver() {
  pwm.begin();
  configureI2c();
  pwm.setPWMFreq(SERVO_PWM_FREQ);
  delay(10);
}

void recoverServoDriver() {
  Wire.end();
  initServoDriver();
}

// A supply dip can also reset the PCA9685 itself, which silently drops it
// back to its power-on prescale and sleep mode: writes still succeed but
// no servo moves. Its prescale register is the cheapest tell.
void ensureServoDriver() {
  uint8_t expected = (uint8_t)(round(25000000.0 / (4096.0 * SERVO_PWM_FREQ)) - 1);
  if (pwm.readPrescale() != expected) recoverServoDriver();
}

unsigned long paddleOpenedAt[MAX_MODULES] = {0};

int servoPulse(int pulse) {
  return constrain(pulse, 120, 490);
}

int moduleForChannel(int channel) {
  int rel = channel - moduleChannelOffset;
  if (rel < 0) return 0;
  int module = rel / 3 + 1;
  return module <= maxModuleForOffset() ? module : 0;
}

int servoSlotForChannel(int channel) {
  return moduleForChannel(channel) ? (channel - moduleChannelOffset) % 3 : -1;
}

void setServoPosition(int channel, int pulse) {
  int value = servoPulse(pulse);
  int pushModule = moduleForChannel(channel);
  if (pushModule && servoSlotForChannel(channel) == 2 &&
      value != servoPulse(moduleConfig[pushModule - 1].pusherNeutral)) {
    lowerPaddleForPush(pushModule);
  }
  if (pwm.setPWM(channel, 0, value) != 0) {
    recoverServoDriver();
    pwm.setPWM(channel, 0, value);
  }
  lastServoMoveAt = millis();
  servosReleased = false;

  int module = moduleForChannel(channel);
  if (module && servoSlotForChannel(channel) == 1) {
    bool open = value == servoPulse(moduleConfig[module - 1].paddleOpen);
    paddleOpenedAt[module - 1] = open ? (millis() | 1) : 0;
  }
}

void lowerPaddleForPush(int module) {
  if (paddleOpenedAt[module - 1] == 0) {
    setServoPosition(getChannel(module, 1), moduleConfig[module - 1].paddleOpen);
  }
  unsigned long elapsed = millis() - paddleOpenedAt[module - 1];
  if (elapsed < DELAY_PADDLE) waitMs(DELAY_PADDLE - elapsed);
}

// SG90s keep hunting around a held position and pick up supply noise as
// twitches, so idle positional servos get no signal at all. Gear friction
// holds them in place. The feeder is left alone: stopFeeder() already
// releases it, and a calibration preview keeps it running on purpose.
void releaseIdleServos() {
  if (servosReleased || millis() - lastServoMoveAt < SERVO_IDLE_RELEASE_MS) {
    return;
  }
  for (int m = 1; m <= maxModuleForOffset(); m++) {
    for (int s = 0; s < 3; s++) pwm.setPin(getChannel(m, s), 0);
    paddleOpenedAt[m - 1] = 0;
  }
  servosReleased = true;
}

void setModuleNeutral(int module) {
  ModuleConfig& c = moduleConfig[module - 1];
  setServoPosition(getChannel(module, 0), c.bottomClosed);
  setServoPosition(getChannel(module, 1), c.paddleClosed);
  setServoPosition(getChannel(module, 2), c.pusherNeutral);
}

void stopFeeder() {
  pwm.setPin(getFeederChannel(), 0);  // cut PWM signal entirely to stop 360° servo
}

// The last card in the hopper has nothing behind it to push it fully in, so
// once the hopper's empty, keep the motor running settleDuration ms longer.
void rollBackFeeder() {
  if (feederConfig.reverseDuration <= 0 || !hopperHasCards()) return;
  setServoPosition(getFeederChannel(), feederConfig.reverseSpeed);
  waitMs(feederConfig.reverseDuration);
  stopFeeder();
}

void settleAndStopFeeder() {
  if (!hopperHasCards()) {
    waitMs(feederConfig.settleDuration);
  }
  stopFeeder();
  rollBackFeeder();
}

// Pulses the feeder, polling module 1's IR between pulses (continuous if
// pulseDuration is 0). Returns FEED_EMPTY only if the hopper was already
// empty AND no card is waiting at module 1 - once feeding starts, the
// hopper going empty just means this is the last card and must not abort
// the feed. routeCard() also calls this again as a presence check right
// before routing, so module 1 must be checked before the hopper check, or
// the last card (hopper already empty by then) gets misreported as absent.
FeedResult runFeeder() {
  unsigned long start = millis();

  if (digitalRead(irPin(1)) == LOW) return FEED_DETECTED;

  if (!hopperHasCards()) {
    setServoPosition(getFeederChannel(), feederConfig.speed);
    waitMs(feederConfig.pulseDuration > 0 ? feederConfig.pulseDuration : 200);
    stopFeeder();
    if (digitalRead(irPin(1)) == LOW) return FEED_DETECTED;
    if (!hopperHasCards()) return FEED_EMPTY;
  }

  if (feederConfig.pulseDuration <= 0) {
    setServoPosition(getFeederChannel(), feederConfig.speed);
    while (millis() - start < (unsigned long)feederConfig.duration) {
      if (digitalRead(irPin(1)) == LOW) {
        settleAndStopFeeder();
        return FEED_DETECTED;
      }
      waitMs(2);
    }
    stopFeeder();
    return FEED_TIMEOUT;
  }

  while (millis() - start < (unsigned long)feederConfig.duration) {
    if (digitalRead(irPin(1)) == LOW) return FEED_DETECTED;

    setServoPosition(getFeederChannel(), feederConfig.speed);

    unsigned long pulseStart = millis();
    while (millis() - pulseStart < (unsigned long)feederConfig.pulseDuration) {
      if (digitalRead(irPin(1)) == LOW) {
        settleAndStopFeeder();
        return FEED_DETECTED;
      }
      waitMs(2);
    }

    stopFeeder();
    if (digitalRead(irPin(1)) == LOW) {
      // Motor's already off - only the last card (hopper now empty) needs an extra push to fully seat it.
      if (!hopperHasCards()) {
        setServoPosition(getFeederChannel(), feederConfig.speed);
        waitMs(feederConfig.settleDuration);
        stopFeeder();
      } else {
        rollBackFeeder();
      }
      return FEED_DETECTED;
    }
    waitMs(feederConfig.pauseDuration);
  }
  return FEED_TIMEOUT;
}
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
void loop() {
  feedWatchdog();
  pumpInput();
  checkModuleJams();
  releaseIdleServos();
#if defined(RGB_BUILTIN)
  updateStatusLed();
#endif
}

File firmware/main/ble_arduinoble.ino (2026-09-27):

// BLE backend for the Arduino Uno R4 WiFi, using the ArduinoBLE library
// (talks to the board's onboard ESP32-S3 co-processor - this is NOT the
// ble_esp32.ino backend, which targets a standalone ESP32-S3 running its own
// sketch directly; ArduinoBLE's API shape is entirely different from
// Bluedroid's). Implements the same bleInit()/blePoll()/bleIsConnected()/
// bleSendLine() contract as ble_esp32.ino so main.ino never branches on
// which backend is active - see main.ino's BLE_SUPPORTED/BLE_BACKEND_*
// macros for the board gating.
//
// Requires the ArduinoBLE library (added to firmware-release.yml's and
// firmware-pr-check.yml's `arduino-cli lib install` steps) - it does not
// ship with the arduino:renesas_uno core the way ESP32's BLE does with its
// core.
#if BLE_BACKEND_ARDUINOBLE
#include <ArduinoBLE.h>

// Nordic UART Service (NUS) - see ble_esp32.ino for the UUID rationale. Must
// match exactly, since the web client looks for one fixed service regardless
// of which board it's talking to.
BLEService nusService("6E400001-B5A3-F393-E0A9-E50E24DCCA9E");
BLECharacteristic rxChar("6E400002-B5A3-F393-E0A9-E50E24DCCA9E",
                          BLEWrite | BLEWriteWithoutResponse, MAX_CMD_LEN);
BLECharacteristic txChar("6E400003-B5A3-F393-E0A9-E50E24DCCA9E", BLERead | BLENotify,
                          MAX_CMD_LEN);

// ArduinoBLE doesn't expose an app-level MTU request, so don't assume a
// negotiated MTU larger than the BLE default actually took effect - chunk
// conservatively at the default ATT MTU's usable payload (23-byte MTU -
// 3-byte ATT header). Verify on hardware whether this can be raised, and
// whether back-to-back writeValue() calls need the delay below (forum
// reports suggest rapid consecutive notifications can be dropped).
#define BLE_CHUNK_SIZE 20
#define BLE_BEGIN_ATTEMPTS 5
#define BLE_BEGIN_RETRY_MS 500

bool bleAvailable = false;

// Manual prototype, belt-and-suspenders alongside main.ino's early
// #include <ArduinoBLE.h> - see that file's comment on why the Arduino
// builder's auto-generated prototypes need BLEDevice/BLECharacteristic
// visible before this function's first (hoisted) declaration.
void onRxWritten(BLEDevice central, BLECharacteristic characteristic);

void onRxWritten(BLEDevice central, BLECharacteristic characteristic) {
  int len = characteristic.valueLength();
  const uint8_t* value = characteristic.value();
  for (int i = 0; i < len; i++) {
    feedByte(bleInput, (char)value[i], bleReply);
  }
}

void bleInit() {
  // BLE.begin() can fail (e.g. co-processor not responding) - there's no
  // channel to report that today beyond Serial staying available regardless,
  // matching how a missing/broken Serial connection is also silently
  // tolerated elsewhere in this firmware.
  for (int attempt = 0; attempt < BLE_BEGIN_ATTEMPTS && !bleAvailable; attempt++) {
    if (BLE.begin()) {
      bleAvailable = true;
    } else {
      BLE.end();
      delay(BLE_BEGIN_RETRY_MS);
    }
  }
  if (!bleAvailable) return;

  // BLE.address() only returns a real value once the co-processor has
  // answered BLE.begin(), unlike ble_esp32.ino's backend, which can read its
  // factory MAC before init - so the ID/name are computed here instead. This
  // is the only source of deviceId for this board (Uno R4 WiFi has no
  // separate esp_read_mac()-style API of its own), so if BLE.begin() had
  // failed above, setup()'s EEPROM fallback (loadOrCreateDeviceId()) takes
  // over instead once it sees deviceId is still empty.
  setDeviceIdFromMac(BLE.address().c_str());
  char localName[32];
  snprintf(localName, sizeof(localName), "Mault Sorter %s", deviceId);

  BLE.setLocalName(localName);
  BLE.setAdvertisedService(nusService);
  nusService.addCharacteristic(rxChar);
  nusService.addCharacteristic(txChar);
  BLE.addService(nusService);
  rxChar.setEventHandler(BLEWritten, onRxWritten);
  BLE.advertise();
}

void blePoll() {
  // Pumps ArduinoBLE's internal event loop - this is what actually invokes
  // onRxWritten() and keeps BLE.connected()/advertising state current.
  static bool polling = false;
  if (polling || !bleAvailable) return;
  polling = true;
  BLE.poll();
  polling = false;
}

bool bleIsConnected() { return bleAvailable && BLE.connected(); }

const char* bleState() {
  if (!bleAvailable) return "unavailable";
  return BLE.connected() ? "connected" : "advertising";
}

void bleSendLine(const char* s) {
  if (!bleIsConnected()) return;
  size_t len = strlen(s);
  // Chunk the line across multiple writeValue() calls, then send a trailing
  // "\n" chunk so the client's byte-stream line-splitter (the same logic it
  // already uses for Serial's byte stream) sees identical framing over BLE
  // as over USB, regardless of chunk boundaries.
  for (size_t offset = 0; offset < len; offset += BLE_CHUNK_SIZE) {
    size_t chunkLen = len - offset < BLE_CHUNK_SIZE ? len - offset : BLE_CHUNK_SIZE;
    txChar.writeValue((const uint8_t*)(s + offset), chunkLen);
    delay(10);  // verify on hardware whether this is actually needed
  }
  txChar.writeValue((const uint8_t*)"\n", 1);
}
#endif  // BLE_BACKEND_ARDUINOBLE

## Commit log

2026-09-26 add calibration tutorial
2026-09-27 fix card session time, and jam issue with firmware
    [main.ino]
2026-09-27 add close buttons to toasts
2026-09-27 add camera selector to the calibration page
2026-09-28 fix support toast buttons
2026-09-28 only allow updating calibrations if no session is running
2026-09-28 add rest calibrations
2026-09-30 switch to storing cards in object storage
2026-10-01 updating wiring diagram
2026-10-01 update 3d files
    [card_sorter.3mf]
2026-10-01 update feature list
    [card_sorter.3mf]
2026-10-01 add discord filtering
2026-10-01 add servo buy link
2026-10-01 group like buttons together
2026-10-02 rollback calibrations
2026-10-02 add device playground and upate kit testing
2026-10-02 fix camera not resizing to fit
2026-10-03 add device management page
2026-10-04 clear query button
